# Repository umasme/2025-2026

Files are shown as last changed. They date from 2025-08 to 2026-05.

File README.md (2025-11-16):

# 🚀 NASA Lunabotics 2026 — University of Miami ASME

Robust, ROS 2–based software stack and supporting assets for our lunar excavation rover.  
This repository houses **software, hardware, simulation, datasets, and documentation** to support the NASA Lunabotics 2026 competition.  

---
## To Build
1. Download Docker
2. Open VS Code and switch to WS directory
3. Install the dev containers extension
4. Control + Shift + P to access command palette
5. Search for Dev Containers: Reopen in Container
6. Voila

## Sensors
1. D435i (TBD)
2. Oak D-lite (TBD)
3. Power sensor
4. Encoders
5. Linear encoders
6. Cameras

## Actuators
1. Four motors
2. Linear Actuators

## After Each Commit
Update DEVLOG.md with a summary of changes. Commits shall be made to the develop branch after main branch docker is working.

## 📖 Project Overview

Our rover integrates:

- **Perception** — stereo depth, object detection, terrain mapping  
- **Localization & Navigation** — SLAM, sensor fusion, path planning  
- **Autonomy** — state machines / behavior trees for excavation & hauling  
- **Control & Teleop** — motor drivers, teleop interfaces, web dashboard  
- **Simulation** — Ignition Gazebo worlds, scenarios, and URDF models  
- **Documentation** — aligned with NASA Systems Engineering (SRR, PDR, CDR, ConOps)  

---

## 📂 Repository Layout

```text
lunabotics-2025/
├─ README.md                     # Project overview (this file)
├─ LICENSE
├─ .github/workflows/            # CI/CD pipelines
├─ .devcontainer/                # VS Code Dev Containers
├─ docker/                       # Development & runtime Dockerfiles
├─ docs/                         # Documentation
│  ├─ index.md
│  ├─ ConOps/                    # SRR/PDR/CDR deliverables
│  ├─ Architectures/             # Block/state diagrams
│  ├─ MissionRules/              # Ops rules, FMEA links
│  ├─ Tutorials/                 # Step-by-step guides
│  └─ Calibration/               # Sensor/actuator calibration
├─ hardware/                     # Mechanical + electrical
│  ├─ electrical/                # Schematics, PCB, BOM
│  ├─ mechanical/                # CAD models, drawings
│  └─ configs/                   # Wiring tables, pin maps
├─ datasets/                     # Large files (via Git LFS)
│  ├─ bags/                      # ROS bag recordings
│  ├─ maps/                      # Occupancy/elevation maps
│  └─ test_scenes/               # Images, point clouds
├─ sim/                          # Simulation assets
│  ├─ worlds/                    # Ignition/Gazebo worlds
│  ├─ models/                    # URDF meshes, STL/DAE
│  └─ scenarios/                 # Scenario configs
├─ examples/                     # Cross-package & full-system demos
│  ├─ sim_demo.launch.py
│  ├─ teleop_example.md
│  └─ rviz_configs/
├─ tools/                        # Utility scripts
│  ├─ log_tools/                 # Bag→CSV, plotting
│  ├─ calibration/               # Camera/IMU calibration
│  ├─ deploy/                    # Deployment helpers
│  └─ ci/                        # CI support scripts
└─ ros2_ws/                      # ROS 2 workspace
   ├─ src/
   │  ├─ lunabotics_bringup/     # System launch & params
   │  ├─ lunabotics_description/ # URDF/Xacro and meshes
   │  ├─ lunabotics_msgs/        # Custom messages & services
   │  ├─ lunabotics_hw/          # Hardware drivers
   │  ├─ lunabotics_perception/  # Cameras, detection
   │  ├─ lunabotics_mapping/     # SLAM & maps
   │  ├─ lunabotics_localization/# State estimation
   │  ├─ lunabotics_navigation/  # Planning & control
   │  ├─ lunabotics_control/     # Low-level control loops
   │  ├─ lunabotics_mission/     # Autonomy FSM/BT
   │  ├─ lunabotics_teleop/      # Joystick / keyboard teleop
   │  ├─ lunabotics_dashboard/   # Web UI & ROS bridge
   │  └─ lunabotics_sim/         # Simulation plugins & launches
   ├─ build/                     # (ignored) colcon build output
   ├─ install/                   # (ignored) colcon install
   └─ log/                       # (ignored) colcon logs

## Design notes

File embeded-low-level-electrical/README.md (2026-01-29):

# 🚀 ASME Lunabotics 2026 University of Miami – Electrical Subsystem

Welcome to the official repository for the electrical subsystem of the University of Miami’s ASME Lunabotics team for the **2026 NASA Lunabotics Competition**.

---

This repository documents the design, implementation, and testing of the rover’s electrical system, emphasizing high reliability, efficiency, and simplicity.

# 2026 Design Goals

- Design an effective system with high reliability, minimal points of failure, and strategic redundancies while keeping it simple with minimal components and maximum efficiency.

- Focus on real-time data logging of current, voltage, power, temperature, and speed for post-analysis and future optimization.
d
- Reduce wiring complexity by using multiplexed communication protocols.

- Ensure reliable wired communication and power distribution to motors and other subsystems.
---
# 2026 Proposed Electrical Architecture

<p align="center">
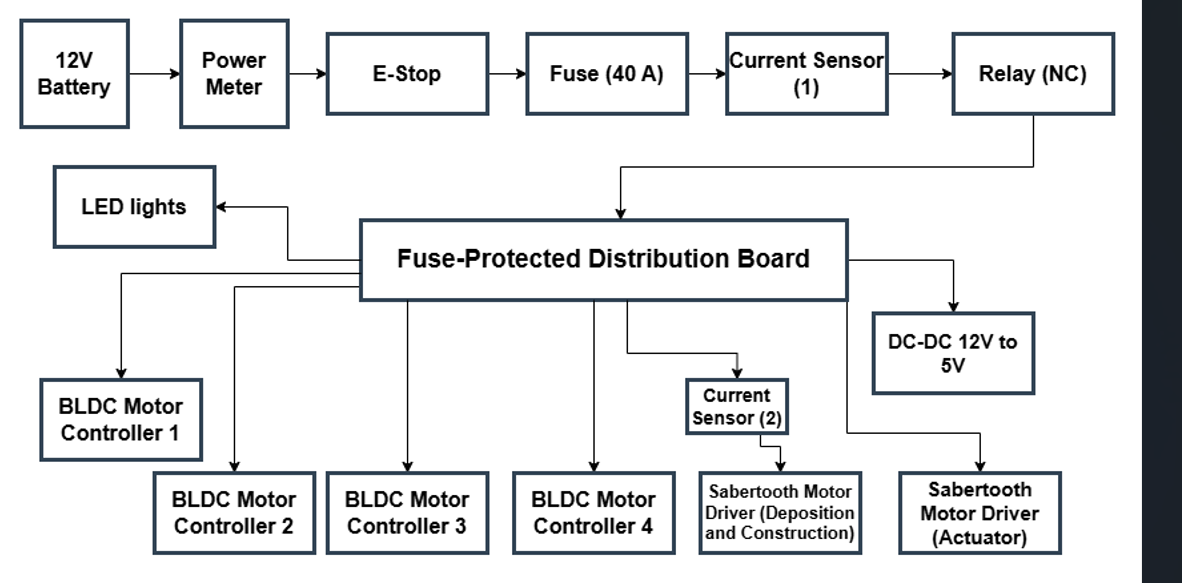
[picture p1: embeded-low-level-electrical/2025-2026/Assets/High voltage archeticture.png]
High Voltage Electrical Architecture
  
  <p align="center">
  <b> High Voltage Electrical Architecture </b>
  </p>
</p>

<p align="center">
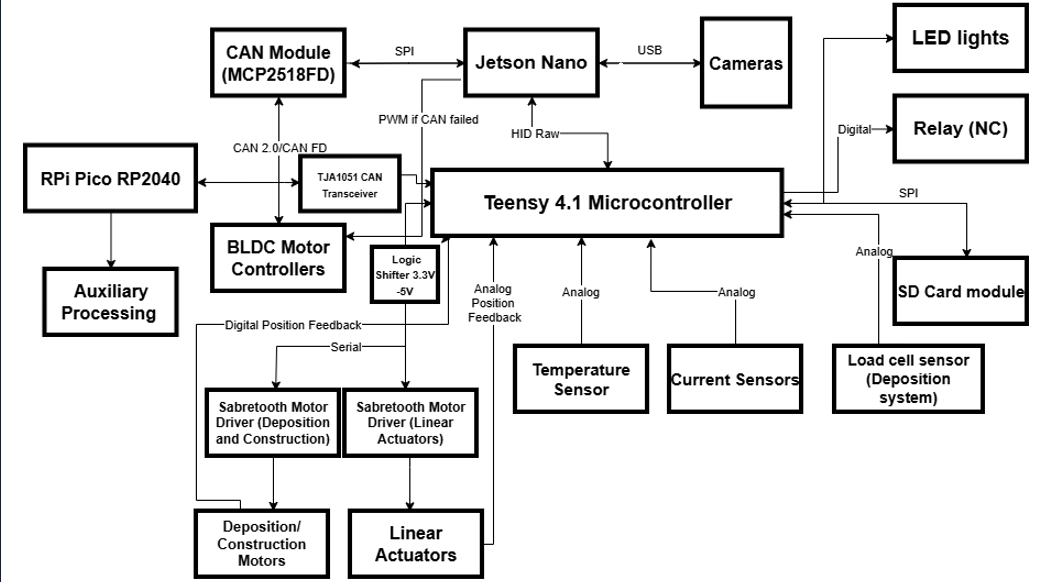
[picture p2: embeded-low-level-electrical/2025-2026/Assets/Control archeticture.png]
Control Electrical Architecture
  
</p>
  <p align="center">
  <b> Control Electrical Architecture </b>
  </p>

---
## Preliminary Design Review (PDR)

As part of the NASA Systems Engineering methodology, our team conducts a **Preliminary Design Review (PDR)** to evaluate and validate the proposed system design before detailed development.  

This review presentation includes:

1. **Responsibilities and Main Goals** – Overview of team roles and project objectives  
2. **Last Year’s System and Proposed Changes** – Comparison and improvements over the previous design  
3. **Design Overview** – High-level architecture and subsystem details  
4. **Verification Plans** – How the design will be tested and validated  
5. **Risk Matrix** – Identification and mitigation of potential risks

📄 **View the PDR presentation:**  
[Electrical PDR – ASME UM (PDF)](https://github.com/umasme/2025-2026/blob/main/embeded-low-level-electrical/2025-2026/Assets/Electrical%20PDR--%20ASME%20UM.pdf)

---
## High-Current Power Distribution Board
This high-current board distributes power to all outputs, including the four drivetrain motors, the excavation motor, the deposition motor, and two linear actuators.

<p align="center">
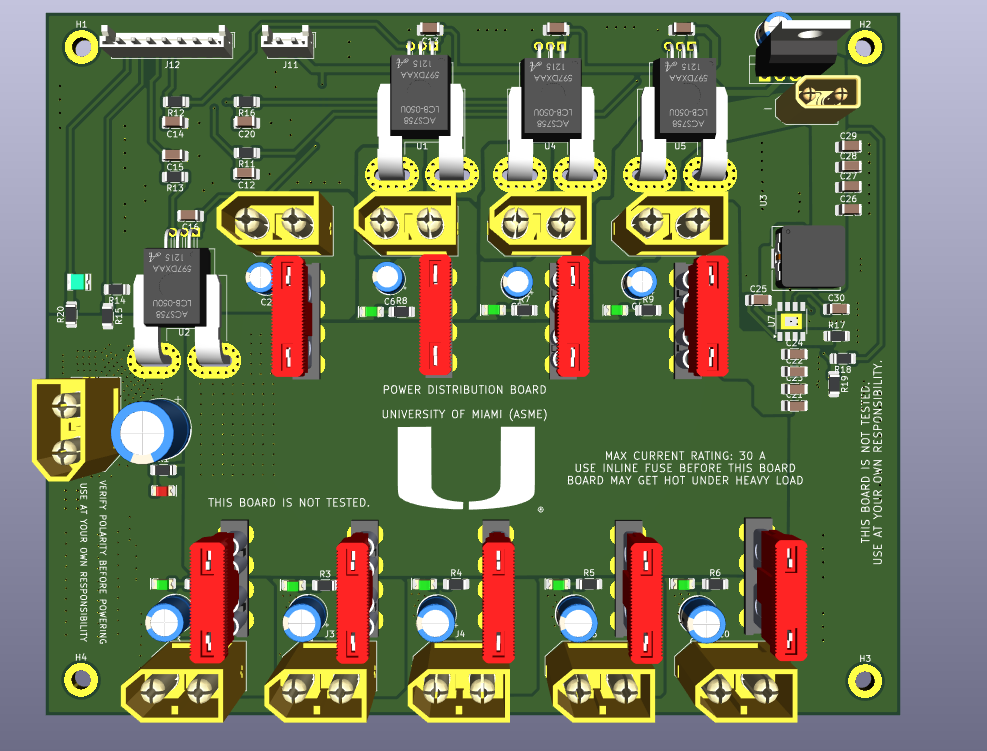
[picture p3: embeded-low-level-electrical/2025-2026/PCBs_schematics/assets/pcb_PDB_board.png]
High-Current Power Distribution Board PCB
  
</p>
<p align="center">
  <b> High-Current Power Distribution Board PCB </b>
</p>

[For more details refer to this link](https://github.com/umasme/2025-2026/tree/main/embeded-low-level-electrical/2025-2026/PCBs_schematics/ASME%20UM%20High%20current%20board%20EDIT%20HERE)

---
## Low-Level Control Board based on Teensy 4.1

<p align="center">
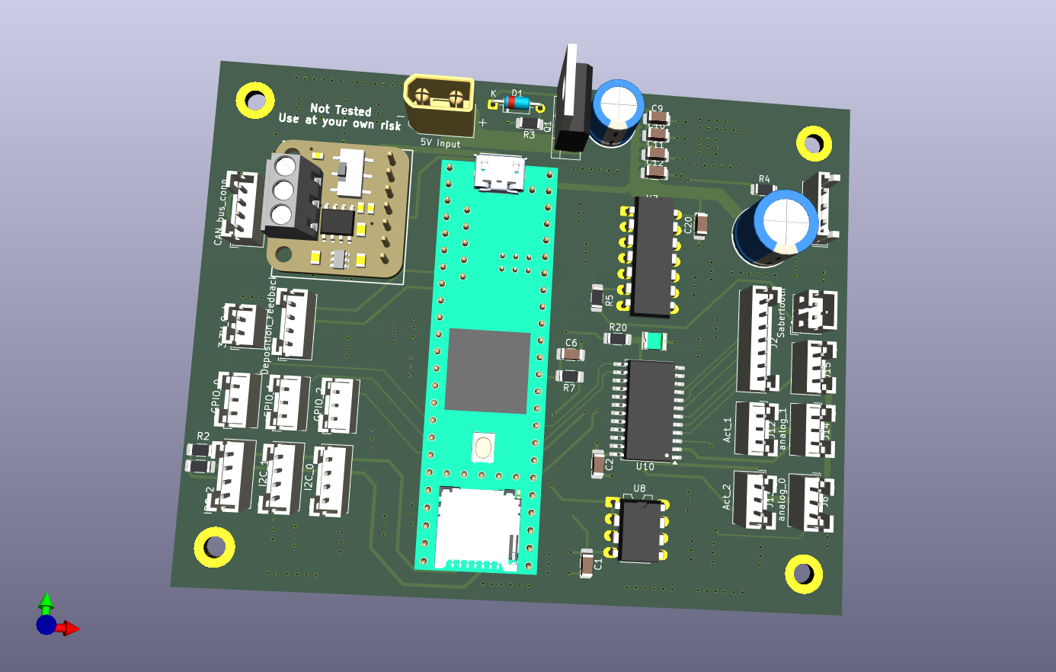
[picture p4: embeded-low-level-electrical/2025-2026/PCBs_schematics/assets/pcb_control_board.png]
Low-Level Control Board based on Teensy 4.1 PCB
  
</p>
<p align="center">
  <b> Low-Level Control Board based on Teensy 4.1 PCB </b>
</p>

[For more details refer to this link](https://github.com/umasme/2025-2026/tree/main/embeded-low-level-electrical/2025-2026/PCBs_schematics/ASME%20UM%20Control%20Board%20EDIT%20HERE)

---
##  🎯2026 Season Plan 
We finalized the season plan for 2026 for the electrical subsystem with detailed performance analysis for each part we used in the electrical system and proposed improvement.

**[Click here to access the 2025 season plan](https://www.overleaf.com/read/gmnmmjygcdmp#dd8f39)**

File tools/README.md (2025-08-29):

### Tools live here
Good tools to have: log tools, calibration, deploy, ci

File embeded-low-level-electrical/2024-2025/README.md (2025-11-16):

# 🚀 ASME Lunabotics 2025 University of Miami – Electrical Subsystem

Welcome to the official repository for the electrical subsystem of the University of Miami’s ASME Lunabotics team for the **2024 NASA Lunabotics Competition**.

---

## 📚 Table of Contents

- [Project Overview](#project-overview)  
- [Achievements](#achievements)  
- [The Rover](#the-rover)  
- [Electrical System Architecture](#electrical-system-architecture)  
- [CAN Bus System](#can-bus-system)  
- [Motor drivers (Sabertooth 2x12)](#motor-drivers-sabertooth-2x12)
- [Motor drivers (BTS7960)](#motor-drivers-bts7960)  
- [Acknowledgement](#acknowledgement)
- [2025 season plan ](#2025-season-plan)
---

## 📌Project Overview

This project highlights main work done by the electrical team of the University of Miami’s **ASME Lunabotics** for the **2024 NASA Lunabotics Competition** — a nationally recognized challenge that tasks university teams with designing and building autonomous lunar excavators capable of navigating and collecting regolith in a simulated lunar environment.

Without hesitation, the **2025 season marked a pivotal turning point** for the team. We built multiple subsystems entirely from scratch, including the complete **electrical subsystem**.
In the design process, we prioritized **simplicity and reliability**, focusing on minimizing points of failure while ensuring high performance in harsh simulated lunar conditions. 

---

## 🏆Achievements

- 🏅 **Leaps and Bounds Award** – For significant improvements in the application of systems engineering. 
- 🥉 **3rd Place in Presentation and Demonstration**  
- ⚡ **Most Energy-Efficient Team**

---

## 🤖The Rover
<p align="center">
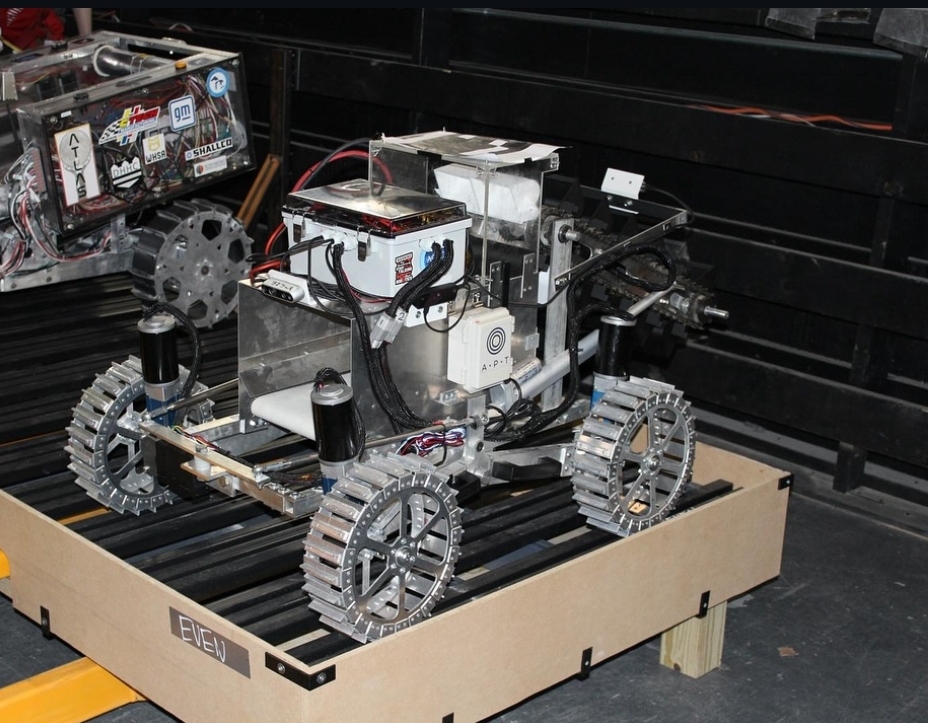
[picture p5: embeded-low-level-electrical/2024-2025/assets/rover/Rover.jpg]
Lunabotics Rover 2024
  
</p>
<p align="center">
  <b>NASA Lunabotics 2025 – Fully Assembled Rover</b><br>
  <a href="assets/">📸 See More Photos</a>
</p>

---

## ⚡Electrical System Architecture
<p align="center">
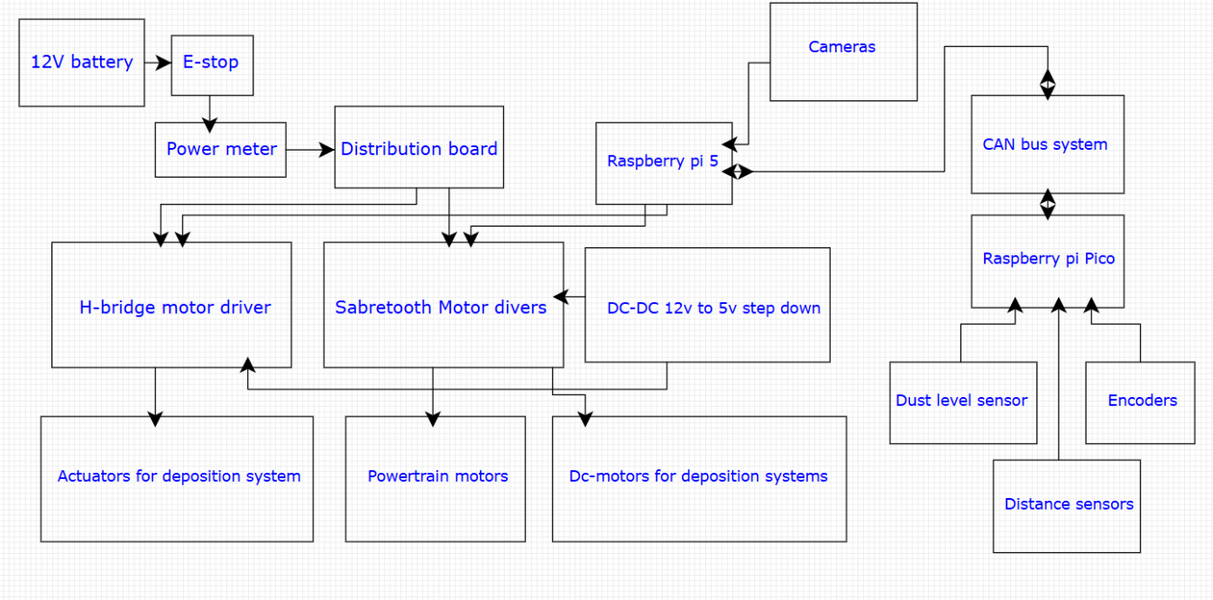
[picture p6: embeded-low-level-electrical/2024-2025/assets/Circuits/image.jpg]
  
</p>
<p align="center">
  <b> Full Simplified Circuit</b>
  </p>
  
  <p align="center">
 <br>
  <a href="assets/Circuits"> Click here to view the full detailed schematics </a>
</p>

---

## 💻 CAN Bus System

The Controller Area Network (CAN) bus is a communication protocol designed for real-time data exchange between electronic devices over a single pair of wires called CAN LOW and the other called CAN HI. Unlike traditional point-to-point serial communication, CAN uses a multi-master architecture where each node (or device) can transmit and receive messages without a central host. Messages are prioritized by IDs, enabling critical data to take precedence during high-traffic periods. CAN also includes error-checking mechanisms like CRC and automatic retransmission, ensuring communication integrity even in electrically noisy environments.  In our rover, the CAN bus linked the **Raspberry Pi** to multiple **Raspberry Pi Pico**, enabling efficient communication of data from sensors and motor encoders. We used CAN bus to reduce the computational load on the main microcontroller, allowing us to distribute this load on multiple nodes. In addition, the CAN bus allowed us to reduce the wire complexity. We used the CAN module **MCP2515** that communicates with the microcontrollers via the SPI and then sends the data through the CAN H and CAN L wires. Note: In this configration, we used the CAN classic 2.0 with data rate of 500 kbit/s.

<p align="center">
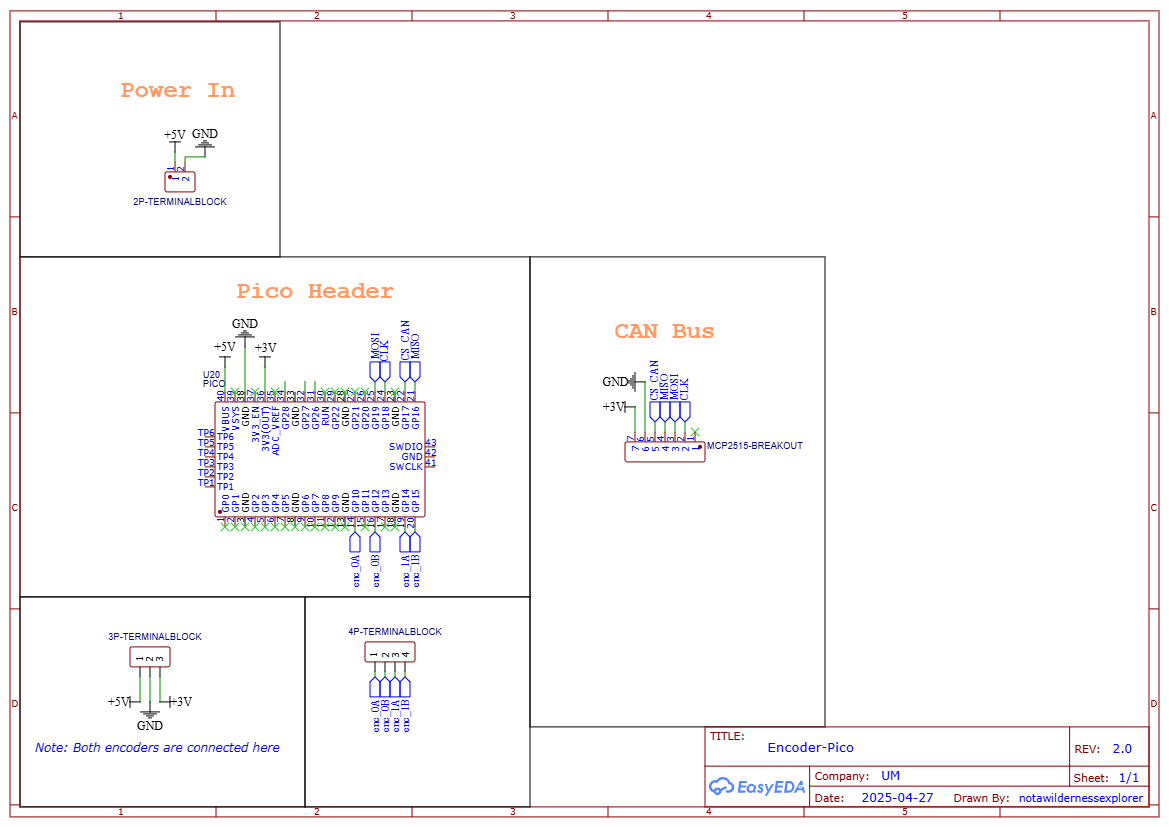
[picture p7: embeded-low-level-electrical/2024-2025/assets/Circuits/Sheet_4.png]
  
</p>
<p align="center">
  <b>CAN bus circuit</b><br>
  <a href="assets/Circuits"> See The complete CAN Circuits</a>
</p>
---
## 🧩 Hardware Setup

This section covers how to connect the MCP2515 and the encoder to the Raspberry Pi Pico.

### 🔌 Wiring

#### MCP2515 → Pico

| MCP2515 Pin | Pico Pin |
|---|---|
| MOSI | GP19 |
| SCK | GP18 |
| MISO | GP16 |
| CS | GP17 |
| VCC | 3V3 |
| GND | GND |

#### Encoder → Pico

| Encoder Pin | Pico Pin |
|---|---|
| 3V | 3.3V |
| 5V | 5V |
| Pin3 | N.C. |
| Pin4 | N.C. |
| B | GP15 |
| Pin6 | N.C. |
| A | GP14 |
| Pin8 | N.C. |
| Pin9 | N.C. |
| GND | GND |

## MCP2515 → Pi 4

| MCP2515 Pin | Raspberry Pi 4 Pin |
|---|---|
| CS | GPIO8 (CE0) |
| MOSI | GPIO10 (MOSI) |
| SCK | GPIO11 (SCLK) |
| MISO | GPIO21 (MISO) |
| INT | GPIO25 |
| VCC | 3.3V |
| GND | GND |

# 🧩 Raspberry Pi MCP2515 Setup

This guide details how to configure a Raspberry Pi to work with an MCP2515 CAN controller module by editing the system configuration file.

---

## 1. Edit the System Config File

First, open the `/boot/firmware/config.txt` file by the following command in terminal.

```bash
sudo nano /boot/firmware/config.txt
```

## 2. Add Overlay Configuration

Next, copy and paste these lines to the end of the `config.txt` file. This tells the Pi to enable the SPI interface and load the necessary driver for the MCP2515 chip.

⚠️ **Important:**

- The `oscillator` value must match the crystal on your specific MCP2515 module. Common values are `8000000` (8 MHz) and `16000000` (16 MHz). You can find this value printed on the crystal of your MCP2515 module.
- The `interrupt` value must match the GPIO pin you connected to the module's `INT` pin.

```ini
# --- MCP2515 CAN Bus Configuration ---
# 1. Enable the SPI bus
dtparam=spi=on
dtoverlay=mcp2515-can0,oscillator=8000000,interrupt=25
```

## ✅ Tips

- Use `loopback=True` first to test.
- When connecting to a real CAN bus, set `loopback=False` and `silent=False`.
- Make sure SPI pins match your Pico’s pinout.

## 📝 Full CAN bus Code with detailed instructions on how to run

👉 **[Click here](CAN%20code)**

---

# 🧩Motor drivers (Sabertooth 2x12)

The Sabertooth 2x12 is a versatile, dual-channel motor driver designed to control two DC motors with up to 12 A continuous current per channel. It supports multiple control modes, including analog, radio control (RC), and serial communication.
---
## You can not plug the Raspberry pi directly to the Sabertooth !! 

One of the challenges we faced was the voltage incompatibility between the **Raspberry Pi**, which operates at 3.3V logic, and the Sabertooth motor driver, which requires 5V logic for reliable serial communication. In the 2023 competition, the team addressed this issue by routing control signals through an **Arduino**, which acted as a 5V buffer. While this worked, it introduced unnecessary complexity and potential communication delays. To make the system simpler and reduce the points of failure, we transitioned to using compact **bi-directional logic level converters (BSS138)**, allowing us to safely and efficiently shift the 3.3V signals up to 5V. This solution maintained signal integrity and enabled direct communication between the Pi and the Sabertooth.

<p align="center">
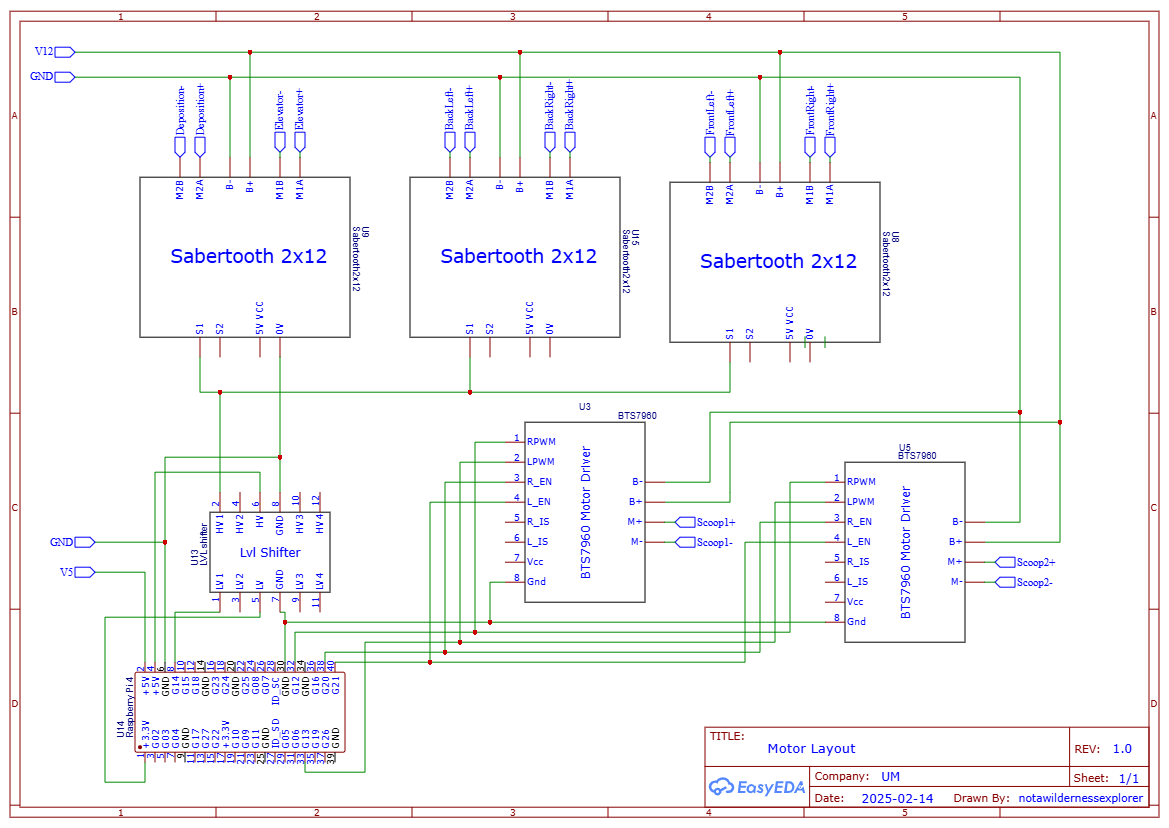
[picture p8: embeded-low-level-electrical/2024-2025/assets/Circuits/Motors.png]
  
</p>

<p align="center">
  <b>Sabertooth and H-bridge Motor Drivers Circuit Schematics </b><br>
</p>

### Sabertooth 2x12 Motor Driver Configuration

To reduce the wiring complexity, the serial mode was used. This explains how to set up the **Sabertooth 2x12** motor driver for **packetized serial mode** with default DIP switch settings and configurable address bits.

📄 [Official Sabertooth 2x12 Datasheet (PDF)](https://www.dimensionengineering.com/datasheets/Sabertooth2x12.pdf)

### ✅ Fixed DIP Switch Settings (#1–#3)

Always make sure the first three DIP switches are set as follows:

| Switch | Position | Purpose |
|:---:|:---:|---|
| 1 | DOWN | Serial mode enabled |
| 2 | DOWN | Baud rate set to 9600 bps |
| 3 | UP | Address bit (fixed) |

### 🔄 Configurable DIP Switches (#4–#6)

Use switches **#4–#6** to set the **serial address**.  
These switches work together with Switch #3 (which is always UP) to define the final address. The documentation above has detailed configration for these switches.

### 🔧 Sample code for testing

To test the motors, we wrote a script using the `pysabertooth` library. Each Sabertooth was initialized with a unique address. This script demonstrates safe testing under current limitations and includes logic for bidirectional control.

```python
from pysabertooth import Sabertooth

# Initialize Sabertooth motor driver on address 128
motor1 = Sabertooth("/dev/serial0", baudrate=9600, address=128)
motor1.open()
motor1.drive(1, 60)  # Drive motor 1 at 60% power
motor1.drive(2, 60)  # Drive motor 2 at 60% power
```

👉 View the full motor test script [here](Main%20codes/motor_testing.py)

---

## 🧩Motor drivers (BTS7960)

---
The BTS7960 is a high-power H-bridge motor driver module capable of driving DC motors with currents up to 43A. This motor driver support speed and direction control via PWM signals. These drivers had beem used to control the linear actuators. 
<p align="center">
  Lunabotics Rover 2024
</p>

<p align="center">
  <b> Sabertooth and H-bridge Motor Drivers Circuit Schematics </b><br>
</p>

| **Pin Name** | **Description** |
| --- | --- |
| **L\_EN** | Left side enable pin (enable left half-bridge) |
| **R\_EN** | Right side enable pin (enable right half-bridge)  |
| **L\_PWM** | Left side PWM input (controls direction/speed) |
| **R\_PWM** | Right side PWM input (controls direction/speed) |
| **RPWM / LPWM** | Alternative labeling for direction control inputs |
| **VCC** | 5V logic power input |
| **GND** | Ground |
| **Motor+** | Motor positive terminal |
| **Motor-** | Motor negative terminal |
| **B+** | Battery positive (motor power input) |
| **B-** | Battery negative (ground) |

If you want to reduce the wiring complexity, you can just PULL L_EN, R_EN, and VCC to be high, and then you can easily control the speed of the actuator by the PWM from only two pins from the PI.

**[Click here to access the test script to run the actuators using H-bridge motor driver](Main%20codes/Actuator.py)**

## 🙏Acknowledgement 

This project was completed under the direct supervision, direct contribution, and mentoring of Russel Roberts, a third-year PhD student studying Physics at the University of Miami. Special thanks for the guidance, expertise, and support provided throughout the development and testing process of this project.

##  🎯2026 Season Plan 
We finalized the season plan for 2026 for the electrical subsystem with detailed performance analysis for each part we used in the electrical system and proposed improvement.

**[Click here to access the 2025 season plan](https://www.overleaf.com/read/gmnmmjygcdmp#dd8f39)**

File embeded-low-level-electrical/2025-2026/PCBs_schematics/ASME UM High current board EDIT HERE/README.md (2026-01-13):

# High-Current Power Distribution Board (PDB)

## Overview
The High-Current Power Distribution Board (PDB) is designed to safely and efficiently distribute electrical power to all high-power subsystems of the rover. It serves as the central power hub, handling high transient currents while providing protection, diagnostics, and future expandability.

## Final Board Design
 Hey!

## Supported Loads
This board distributes power to the following subsystems:

* **4×** Drivetrain motors (BLDC)
* **1×** Excavation motor (BLDC)
* **1×** Deposition motor (DC)
* **2×** Linear actuators 

> **Note:** The Jetson Nano is powered through an external power supply with a dedicated DC-DC converter and is **not** powered directly from this board.

## Electrical Capabilities
* **Peak Current:** Supports up to **40 A** peak current during startup and transient conditions.
* **Output Configuration:**
  * Minimum of **7** high-current outputs.
  * **1** dedicated output for a DC-DC converter.

## Board Features
* **Protection:** Reverse-polarity protection on the main power input and individual fuses for each output bus. (To be added)
* **Diagnostics:**
  * Power indication LED for board power status.
  * Individual LED indicators for each output to identify blown or faulted fuses.
* **Stability:** Decoupling capacitors for voltage stability and noise reduction.
* **Mechanical:** Defined mounting holes for secure mechanical integration.
* **Current Sensing:**
  * Initial revision includes main bus current sensor (or limited sensors).
  * PCB design preserves expandability for future per-output current sensing.
* ** Add-ons:**
  * Onboard DC-DC buck converter based on AP64502Q synchronous DC-DC buck converter (5V/5A). 
  * Linear 3.3 V regulator (not required for current system architecture).

## PCB Design Considerations
* **High-Current Optimization:** Adhered to IPC-2221 standards for power plane optimization to handle high-current loads and manage thermal dissipation.
* **Component Layout:** Strictly followed the recommended layout guidelines specified in the [AP64502Q DC-DC Converter Datasheet](https://www.diodes.com/datasheet/download/AP64502Q.pdf) to minimize noise and ensure stability.
* **Power Integrity Analysis:** Utilized Altium's Power Analyzer tool to simulate current density and eliminate bottlenecks.
<h3>Power Analyzer Results</h3>
<table width="100%">
  <tr>
    <th width="50%">Before Optimization</th>
    <th width="50%">After Optimization</th>
  </tr>
  <tr>
    <td align="center">
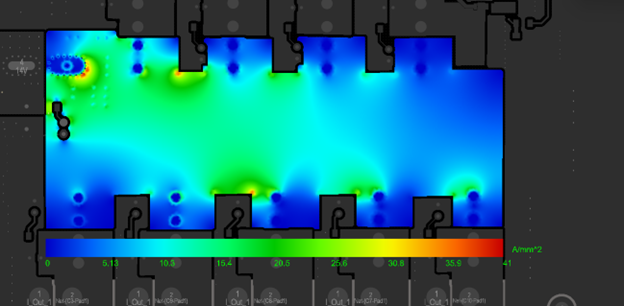
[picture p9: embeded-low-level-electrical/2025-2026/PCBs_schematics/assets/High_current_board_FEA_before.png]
Before
      
    </td>
    <td align="center">
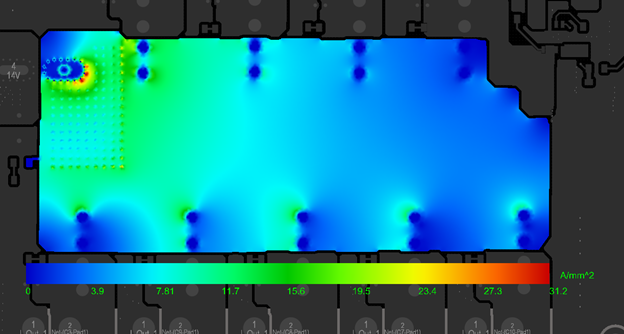
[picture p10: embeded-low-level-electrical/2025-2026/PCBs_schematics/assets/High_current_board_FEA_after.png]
After
      
    </td>
  </tr>
</table>

## Design Objectives
* **Reliability:** Consistent operation under high-current and transient conditions.
* **Efficiency:** Low-resistance power paths to minimize voltage drop.
* **Usability:** Clear visual diagnostics for fast fault identification.

## Safety and Protection
* **Input:** Reverse-polarity protection.
* **Output:** Fuse protection per channel.
* **Visuals:** Fault detection via LED indicators.
* **Noise:** Electrical noise suppression using decoupling capacitors.

## Please Stay Tuned for the fabrication and prototyping

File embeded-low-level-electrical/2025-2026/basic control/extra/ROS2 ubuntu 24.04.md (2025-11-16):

✅ **Here is the installation procedure for ROS 2 Jazzy on a Raspberry Pi 5:**

1. Burn **Ubuntu 24.04 LTS** onto the Raspberry Pi 5 using the **Raspberry Pi Imager**.
2. Follow the installation procedure here: [ROS 2 Jazzy Installation Guide](https://docs.ros.org/en/jazzy/Installation/Ubuntu-Install-Debs.html).
3. When you finish the installation, type `ros2` in the terminal. If it doesn’t work, it’s probably because you still need to source your workspace.
4. Install **gedit** using this command:

   ```bash
   sudo apt update
   sudo apt install gedit -y
   ```
5. Then open `.bashrc` with:

   ```bash
   gedit ~/.bashrc
   ```

   At the end of the file, add:

   ```bash
   source /opt/ros/jazzy/setup.bash
   source ~/ros2_ws/install/setup.bash
   ```

   *(Add the `~/ros2_ws` line only if you have already created and built a workspace.)*
6. Save the file, then type `source ~/.bashrc` to reload it. Now, typing `ros2` in the terminal should work.

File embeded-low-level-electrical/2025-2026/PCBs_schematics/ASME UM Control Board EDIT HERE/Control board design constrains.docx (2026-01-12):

Hi,

In our design we need another low-level control board, which is supposed to have mainly Teensy 4.1 and motor drivers’ controls.

### 1. Core Architecture & Power

- Microcontroller: The board shall utilize a Teensy 4.1 as the primary controller.
- Power Input: The system shall be powered by a 5V DC input from an external Power Distribution Board (PDB).
- Voltage Regulation: The board shall provide a stable 3.3V output rail for external sensors and peripherals.
- Power Integrity: Decoupling capacitors shall be placed at all IC power pins and across power rails to ensure signal stability and suppress high-frequency noise.

### 2. Communication & Motor Control

- I2C Bus:
  - Provide headers for up to three (3) I2C interfaces.
  - Each shall include integrated pull-up resistors sized for the target bus speed.
- SPI Bus:
  - Include a dedicated SPI interface with PCB layout considerations for impedance control and trace length matching.
- CAN Bus:
  - Include a CAN interface utilizing the Teensy 4.1 FlexCAN controller (requires an external transceiver).
- Sabertooth Interface:
  - Provide a dedicated Serial communication interface for Sabertooth motor drivers.
- Logic Level Shifting:
  - Please follow the recommended layout from the TI.
  - Implement unidirectional logic level shifter (SN74AHCT125N) to convert 3.3V Teensy logic to 5V for:
    - Digital LED control signals.
    - Sabertooth motor driver logic (where required).

### 3. Specialized Actuator & Sensor I/O

- Deposition Motor Encoders:
  - Provide a 6-pin interface for motor encoders. This interface shall operate on 3.3V logic as per validated testing.
- Linear Actuators: Support two (2) linear actuators via two 3-pin interfaces.
  - Feedback: The system shall utilize analog input for position feedback from the actuators.
- Analog Inputs: Provide at least five (5) analog input pins (including actuator feedback).
- Signal Conditioning: Implement Op-Amp voltage buffers for high-impedance inputs (e.g., voltage dividers).
  - Note: Active RC filtering is excluded; local decoupling for the Op-Amp IC is mandatory.
- PWM & Interrupt: Include at least one (1) dedicated PWM interface.
  - Reserve a minimum of two (2) interrupt-capable digital pins for E-Stop relay control or limit switches.
- LED lights: Add a capacitor and a resistor to prevent signal reflection on the data signal pin.

### 4. Physical & PCB Design Requirements

- Connectors: All off-board connections shall utilize JST 2.54mm (0.1") connectors for secure, standardized interlocking.
- PCB Stackup: Top Layer: Primary signal routing and component placement.
  - Bottom Layer: Dedicated Ground Plane to minimize EMI and provide a low-impedance return path.
- Trace Geometry: Trace widths shall be calculated using the IPC-2221 standard to ensure manufacturing reliability and mechanical durability, regardless of current load.

Do we need Op amp before the ADC?

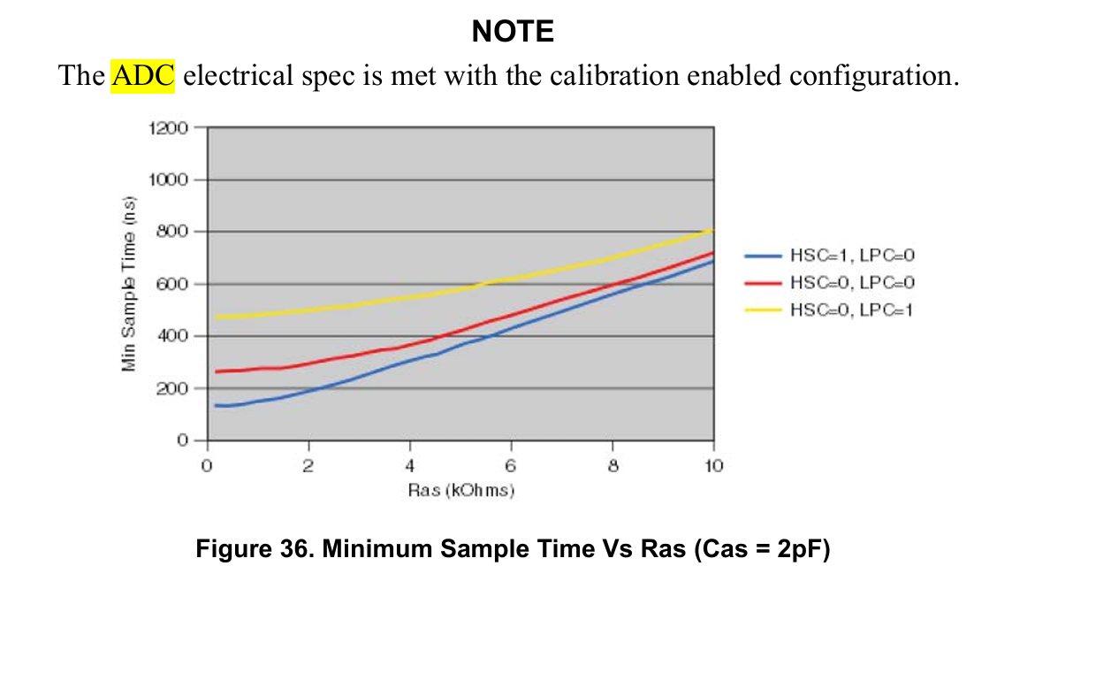
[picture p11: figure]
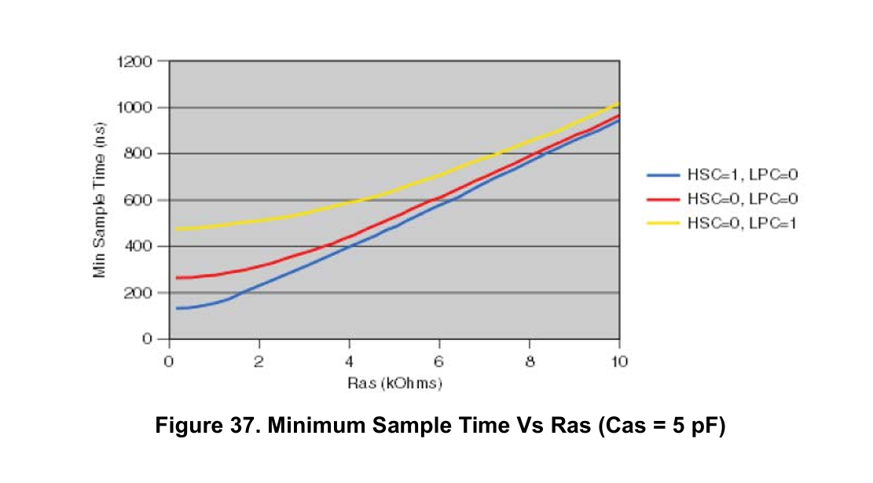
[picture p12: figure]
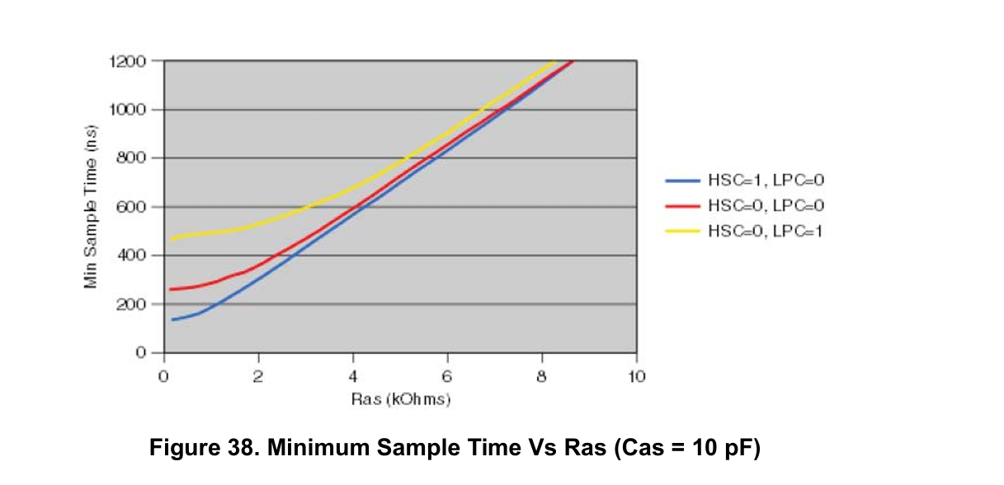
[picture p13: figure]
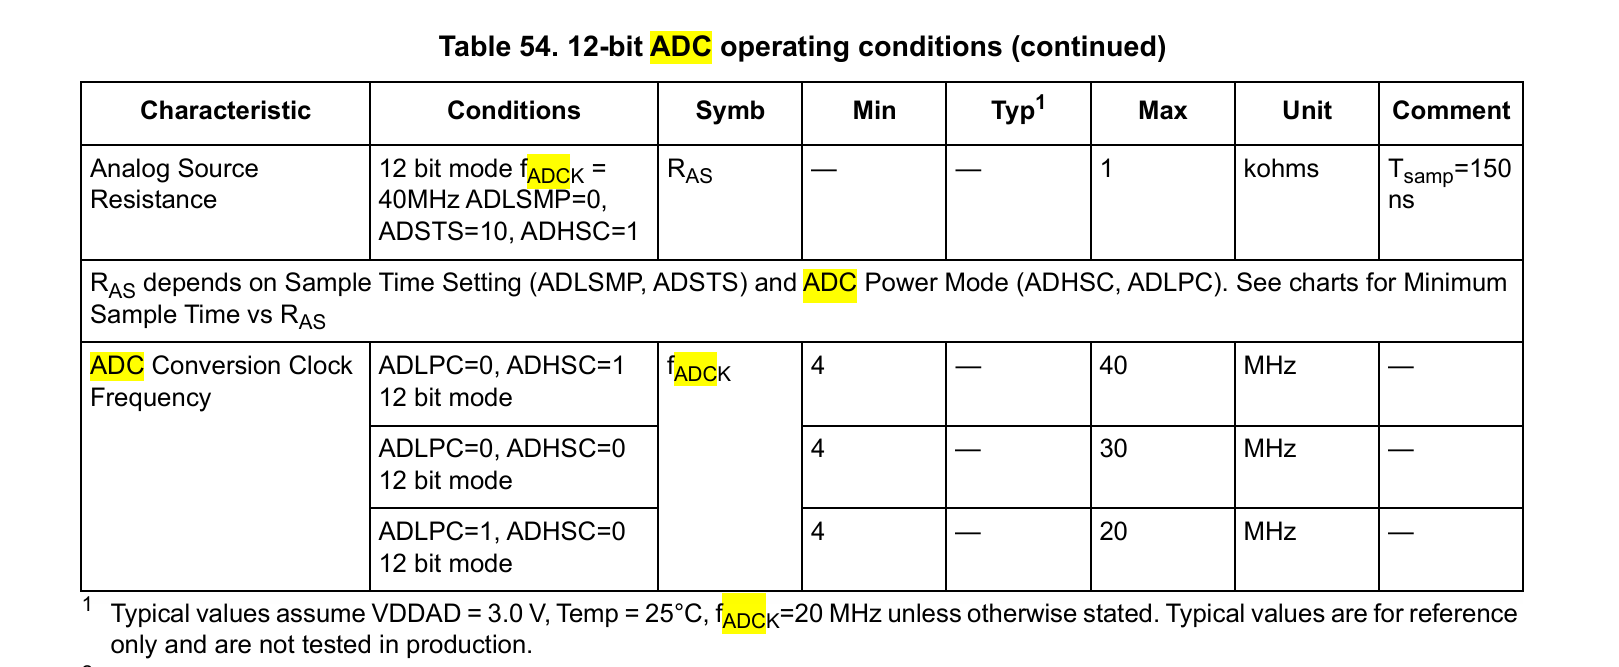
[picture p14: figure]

First of all, there are no pull up resistors on the evaluation board. What about the internal pull up resistors?

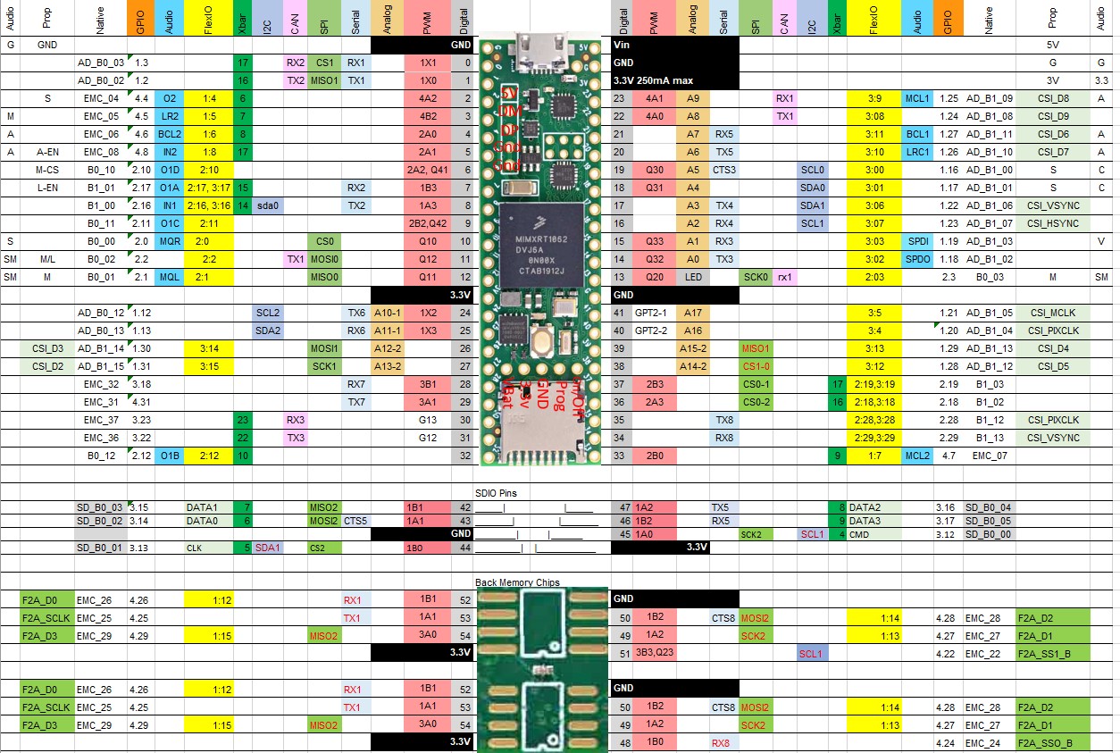
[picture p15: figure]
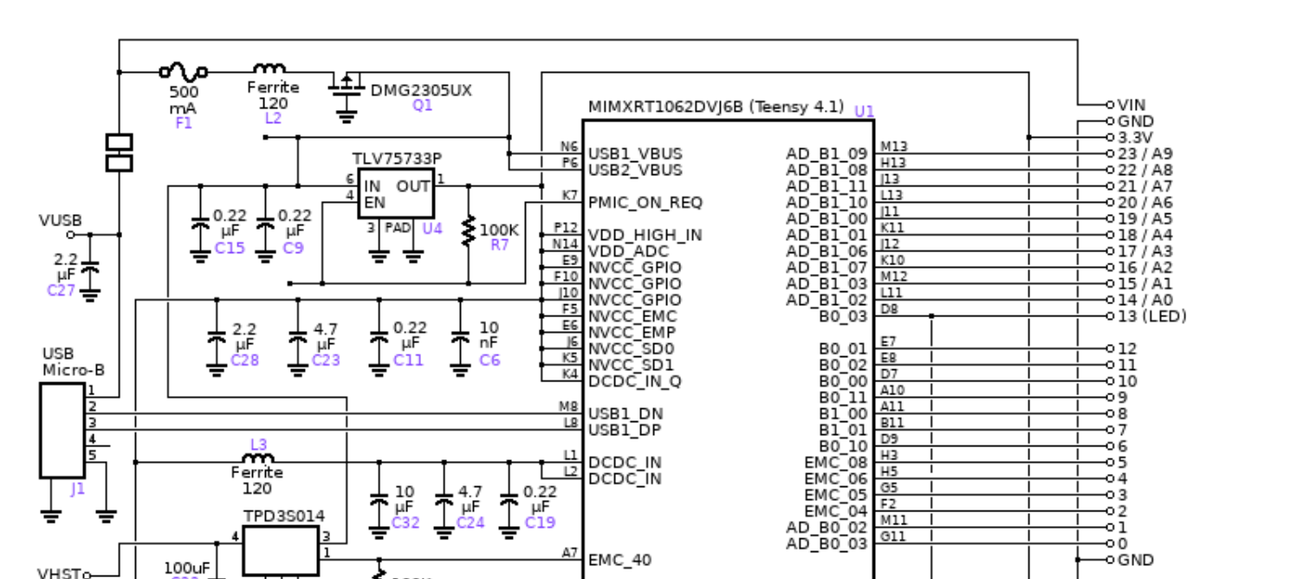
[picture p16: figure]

Teensy and Teensy++ Schematic Diagrams (https://www.pjrc.com/teensy/schematic.html)

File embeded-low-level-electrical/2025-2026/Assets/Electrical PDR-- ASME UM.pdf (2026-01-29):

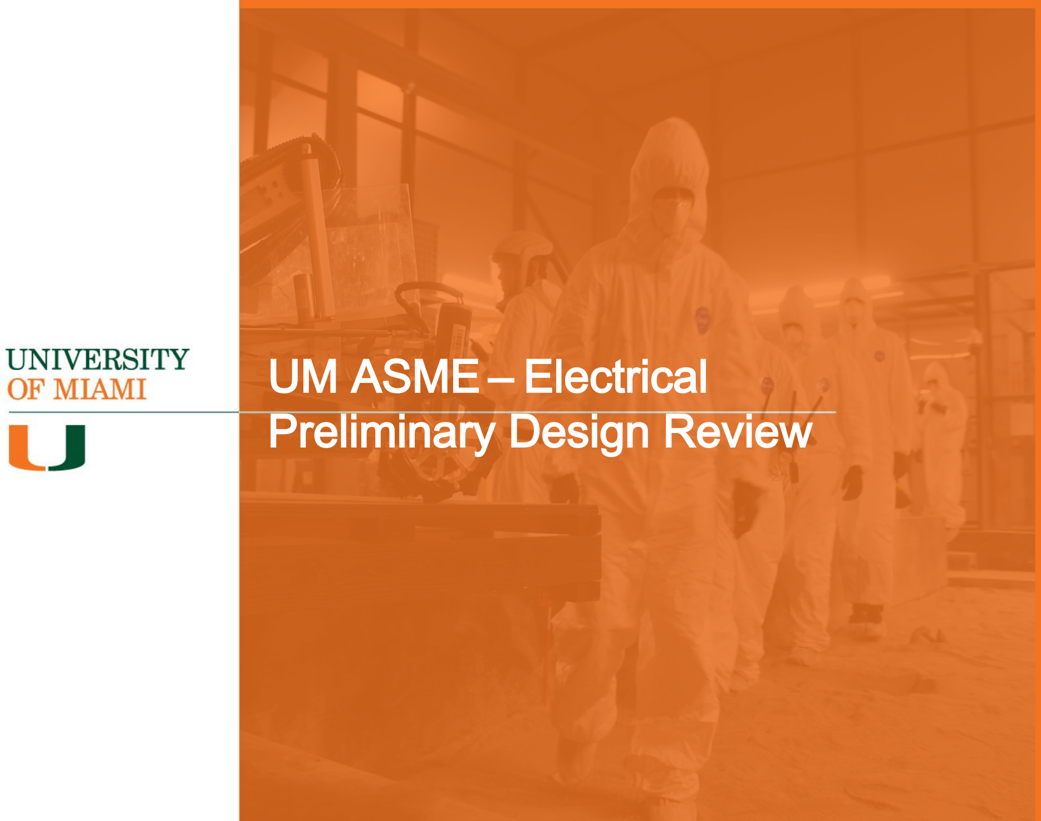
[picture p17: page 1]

# UM ASME – Electrical Preliminary Design Review

# Agenda

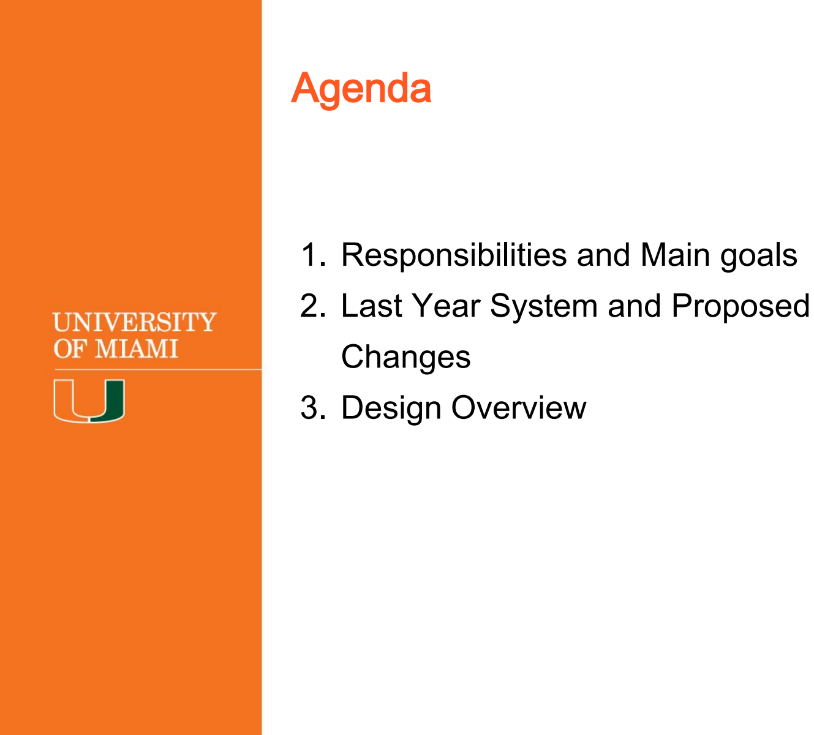
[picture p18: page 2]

# 1. Responsibilities and Main goals 2. Last Year System and Proposed Changes 3. Design Overview

# Electrical Objectives

Our main Objectives are:
1. Design an effective electrical system with high reliability, minimal points of failure, and redundancies while keeping it simple with minimal components and maximum efficiency.
2. Work closely with software and mechanical sub teams to achieve project goals.
3. Focus on real-time data logging of current, voltage, power, temperature, and speed for post-analysis and future optimization.
4. Reduce wiring complexity by using multiplexed communication protocols.
5. Ensure reliable wired communication and power distribution to motors and other subsystems.

# Last Year’s system

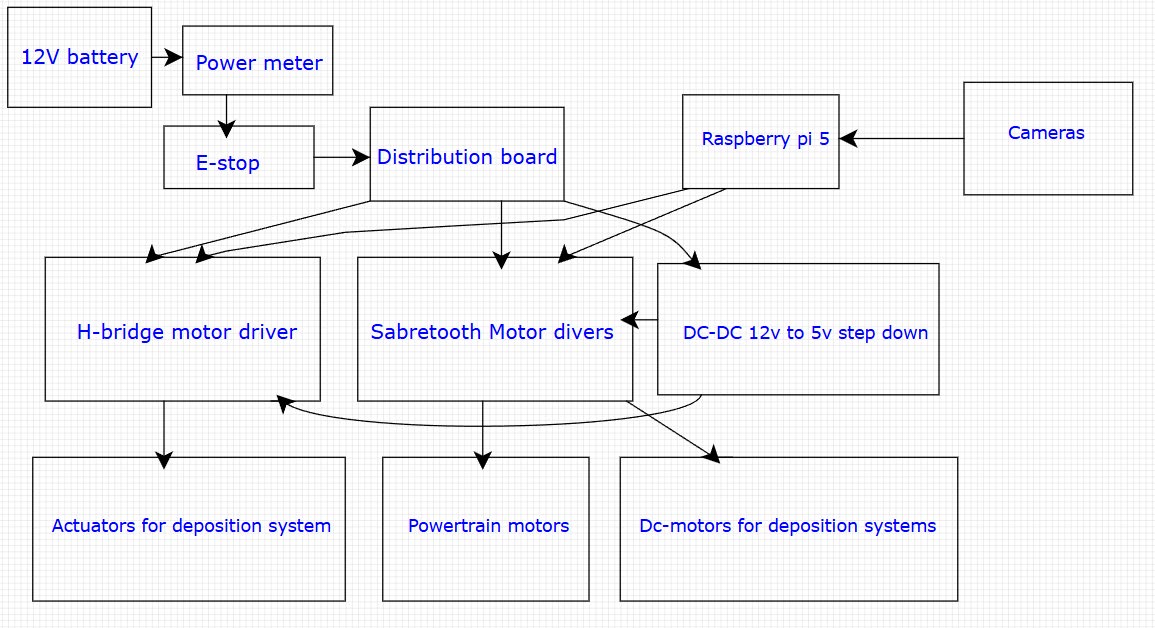
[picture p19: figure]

# Last Year’s system: Challenges and Proposed Changes

CAN Bus Interface:
Challenge
- Logic-level voltage incompatibility between the MCP2515 CAN module and the microcontroller
Solution
- Replaced MCP2515 with MCP2518FD
- Utilized the built-in CAN controller of the Teensy
- Used CAN-to-USB for communication with the main computer (Jetson Nano) via SocketCAN
- Integrated TJA1051T/3 (Adafruit) CAN transceiver
- Includes a built-in logic level shifter
- Ensures reliable voltage compatibility with the CAN

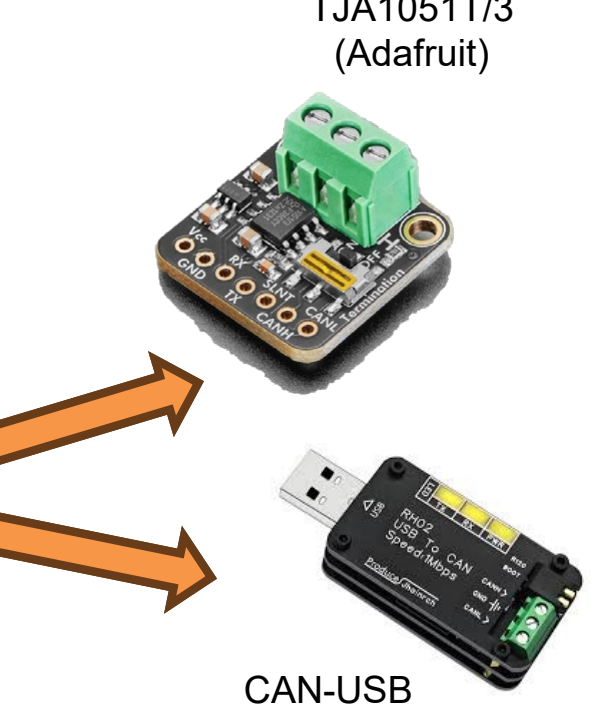
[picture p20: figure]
CAN-USB; (Adafruit)

bus | The Same VCC

MCP2515

TJA1051T/3

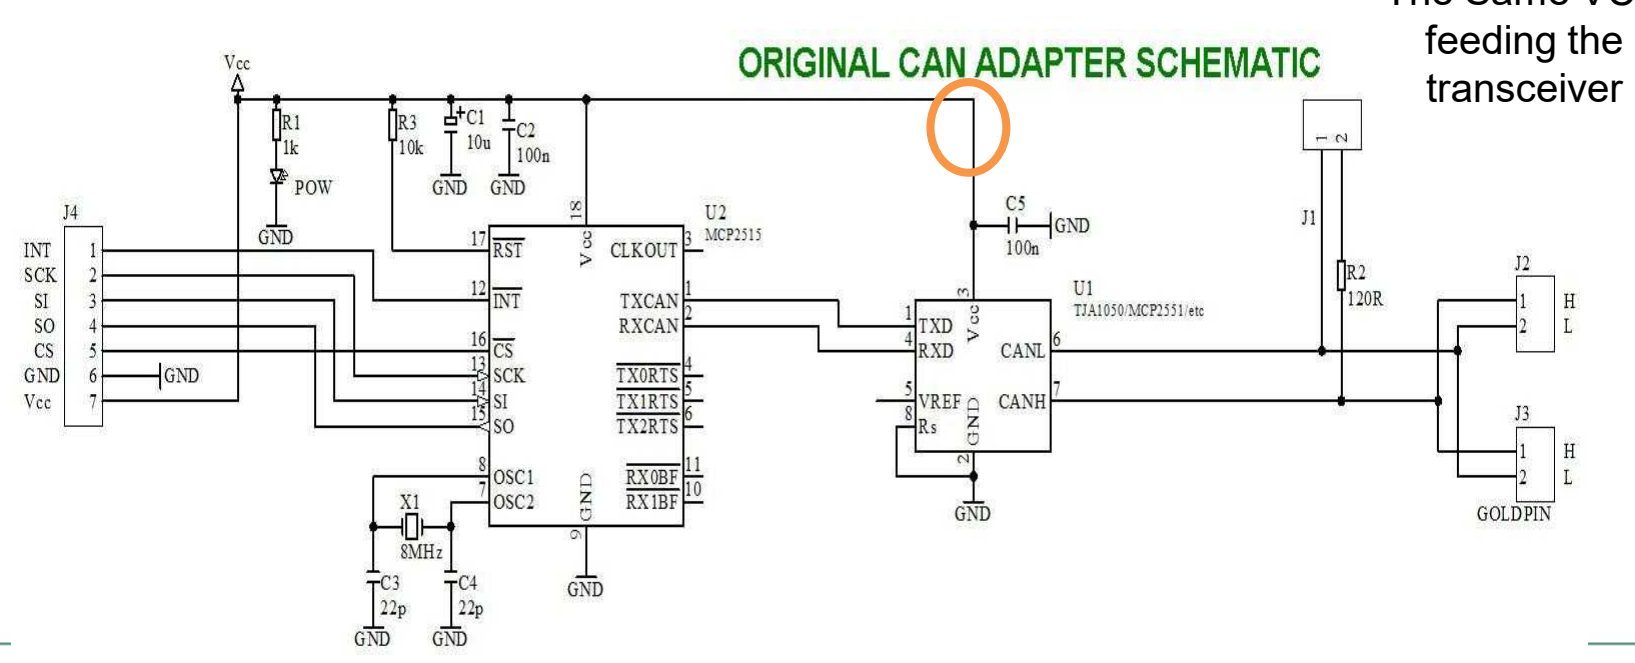
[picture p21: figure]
feeding the transceiver

# Last Year’s system: Challenges and Proposed Changes

Drivetrain motors:
Challenge
- Previous DC motors were heavy, inefficient, and lacked encoders for motion feedback
Solution
- Replaced CIM DC motors with REV Robotics BLDC 1.1V. Key Advantages
- ~60% weight reduction
- ~10% higher efficiency
- Built-in encoder for precise speed and position feedback
- CAN bus communication
- Integrated PID control within the motor controller
- Smaller physical footprint

BLDC Rev
robotics NEO
1.1V

CIM DC motor

# Last Year’s system: Challenges and Proposed Changes BLDC motors

The main issue we are facing is controlling the BLDC motors with CAN bus system. This includes reverse engineering the CAN addresses control and heartbeat signals. We could find the documentation which outlines the addresses for each functionality inside this motor controller as you see below
The team could successfully control the motors

# Last Year’s system: Challenges and Proposed Changes: BLDC motor

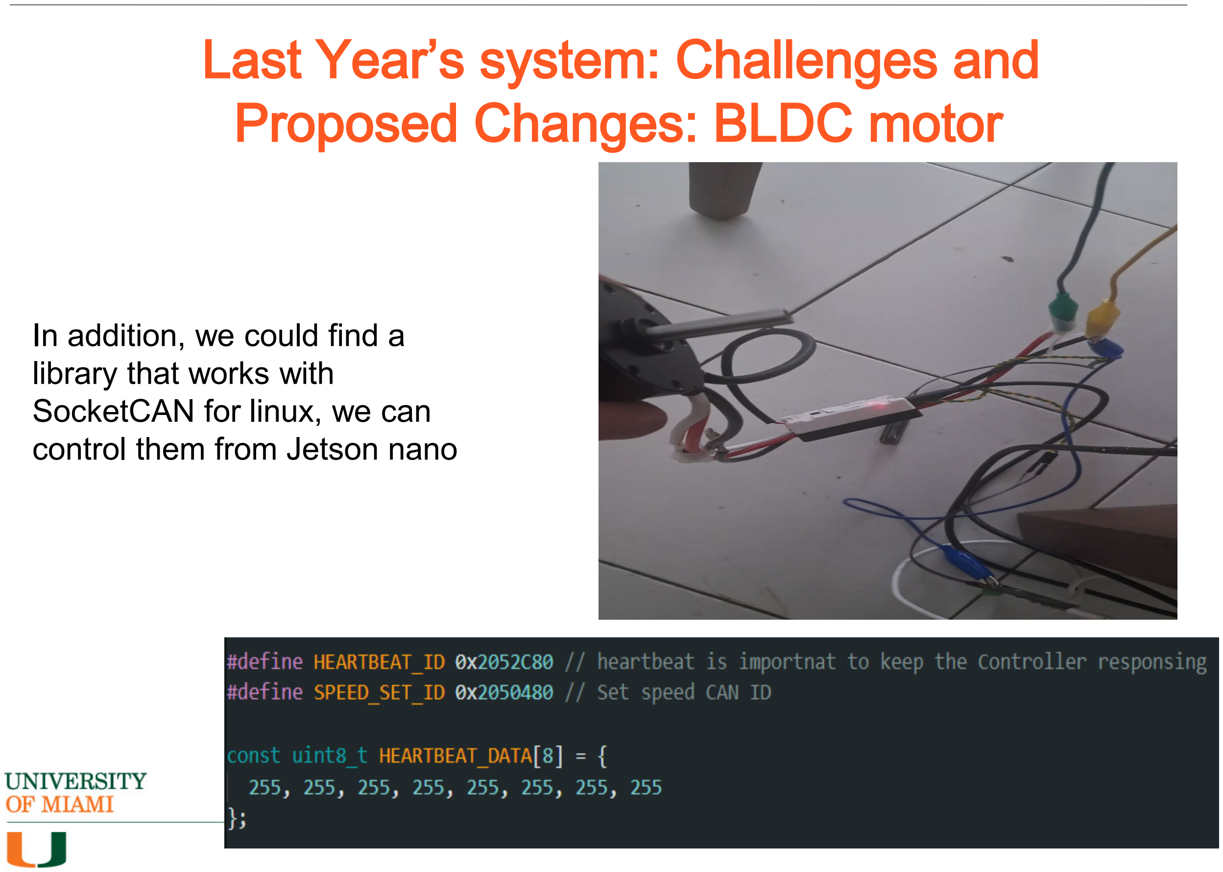
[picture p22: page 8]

### In addition, we could find a library that works with SocketCAN for linux, we can control them from Jetson nano

# Last Year’s system: Challenges and Proposed Changes

Deposition Motor:
Challenge
- Previous DC motor lacked encoders for motion feedback Solution
- Replaced with the same motor with Encoders.

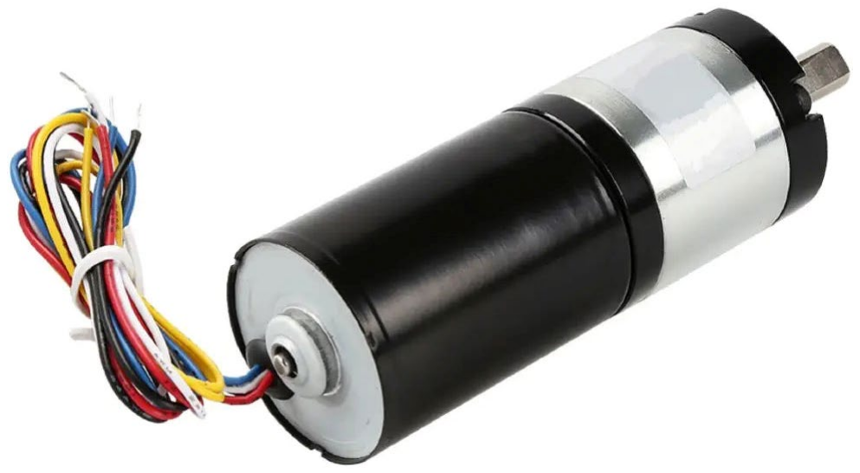
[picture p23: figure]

# Last Year’s system: Challenges and

Batteries : | Proposed Changes

Challenge

Previous LiFePO₄ batteries suffered from:

•Low energy density
•Limited discharge current, restricting motor performance
Solution

Replaced LiFePO₄ batteries with LiPo (Lithium-Polymer) drone batteries

Key Advantages
- 50%–80% higher energy density
- ~50% faster charging time
- Extremely high discharge rate (high C-rating)
→ Supports high motor current demand and rapid acceleration

BLDC Rev
robotics NEO
1.1V

Li-Ion battery

# Electrical Architecture

### 1. High-Current Power Subsystem

Handles power generation and distribution for high-load components. It includes:
- Battery
- Power Distribution Board (PDB)
- Fuses and protection circuitry
- DC-DC converters.

### 2. Low-Voltage Control Subsystem

Responsible for system intelligence, control, and communication. It includes:
- Microcontroller
- Control board
- All control logic and internal communication within the system

### 3. Electrical Interconnects & Enclosure Subsystem

Provides mechanical protection and reliable electrical connectivity. It includes:
- Electrical harnesses
- Electrical connectors
- Electrical enclosure (electrical box)

# Electrical Architecture: High-Current Power Subsystem

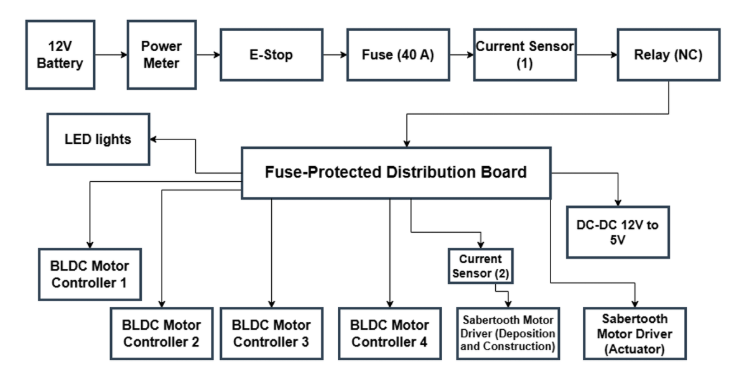
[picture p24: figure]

# Electrical Architecture: High-Current Power Subsystem: PDB


Power Distribution Board (PDB) — Main Functionalities

- Handles up to 40 A peak current during startup and transient conditions
- Provides 7 high-current outputs + 1 dedicated DC-DC converter output
- Fuse protection on each power bus
- Main bus current sensing
- integrated DC-DC buck converter 5V/5A
- Strictly follow the guidelines for the current IPC-2221/IPC-2152 for trace width and copper pour.
- Used the Power analysis tool in Altium to define the areas of high current densities

# PDB: Schematics


# PDB: Schematics: Continued


# PDB: PCB Continued


# PDB: PCB Continued


# PDB: PCB Continued


# PDB: PCB Continued

Before Optimization
- Several high-current hotspots (red/yellow regions) observed
- Current crowding at trace bottlenecks and sharp corners
- Uneven current distribution → potential localized heating and voltage drops.

After Optimization
- High-current hotspots eliminated
- Current evenly distributed across the plane
- Lower current density in critical areas → improved thermal safety
Achieved by:
- Widening traces in high-current regions
- Adding copper pours/planes for better distribution
- Smoothing corners and removing bottlenecks
- Re-routing connections for more uniform flow


# Electrical Architecture: Low Voltage/logic

# Electrical Architecture: Low Voltage/logic


Main Functionalities of the control board are:

- Teensy 4.1 microcontroller with 5V input, regulated 3.3V output, and decoupling for stable operation.
- Supports I2C, SPI, CAN, and serial interfaces for sensors and Sabertooth motor drivers, with logic level shifting for 3.3V 5V signals.
- Interfaces for motor encoders, linear actuators, analog sensors, PWM outputs, interrupt pins, and LED.
- Standard JST connectors, four-layer PCB with two ground plane for low-EMI operation.
- Followed the IPC-2221/IPC-2152 for trade width.

# Control Board: Schematics


# Control Board: Schematics


# Control Board: Schematics


# Control Board: PCB


# Control Board: PCB


# Electrical harnesses and connectors


# Electrical harnesses and connectors


# Electrical Enclosure


# Thank You!

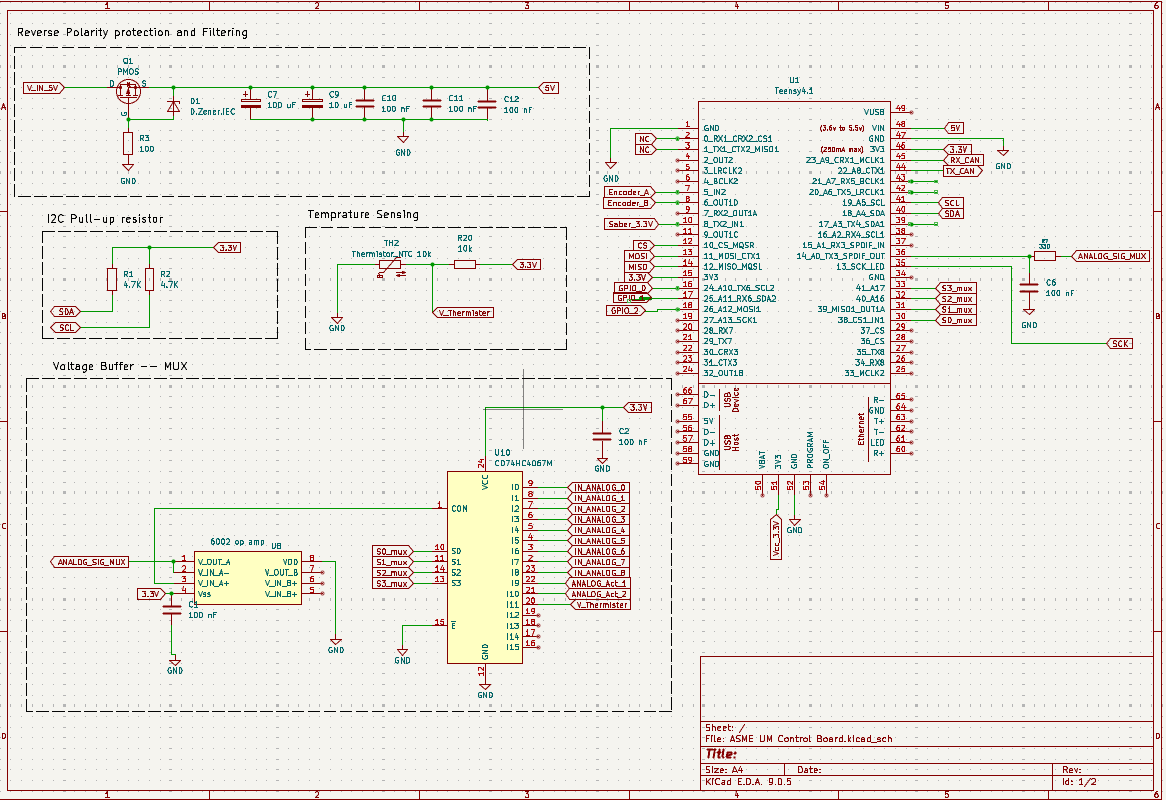
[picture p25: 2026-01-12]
embeded-low-level-electrical/2025-2026/PCBs_schematics/assets/Control_board_schematics.png

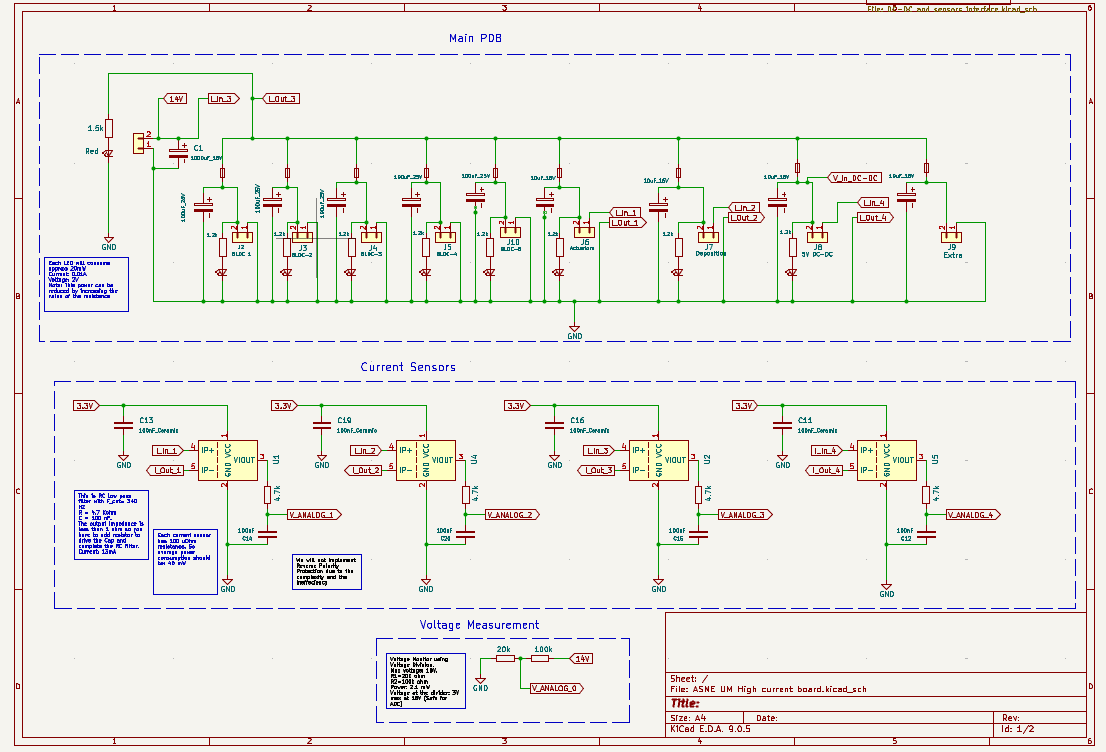
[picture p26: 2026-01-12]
embeded-low-level-electrical/2025-2026/PCBs_schematics/assets/PDB_board_schematics.png

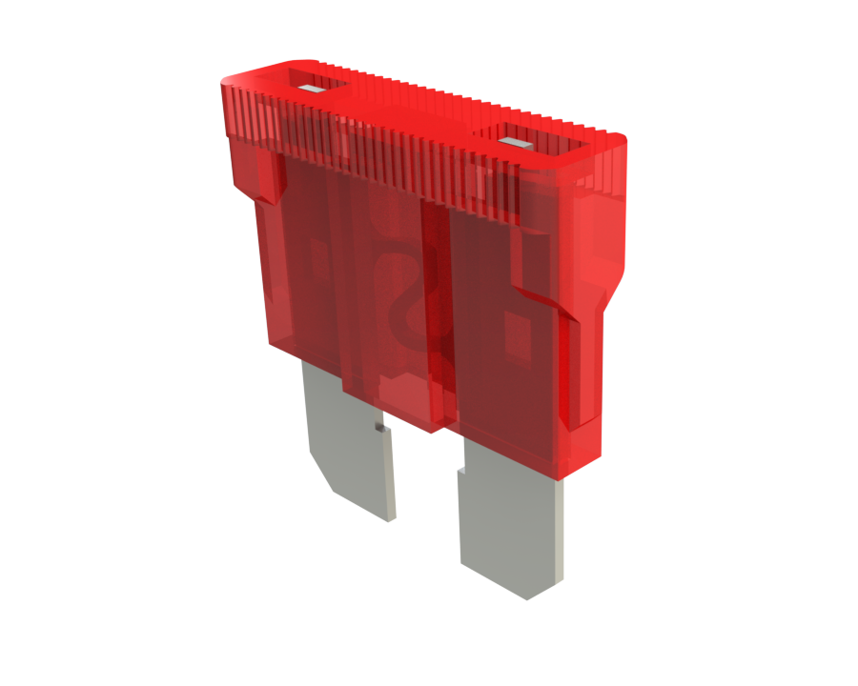
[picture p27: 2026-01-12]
embeded-low-level-electrical/2025-2026/PCBs_schematics/ASME UM High current board EDIT HERE/Footprints/fuse-automotive-10a.png

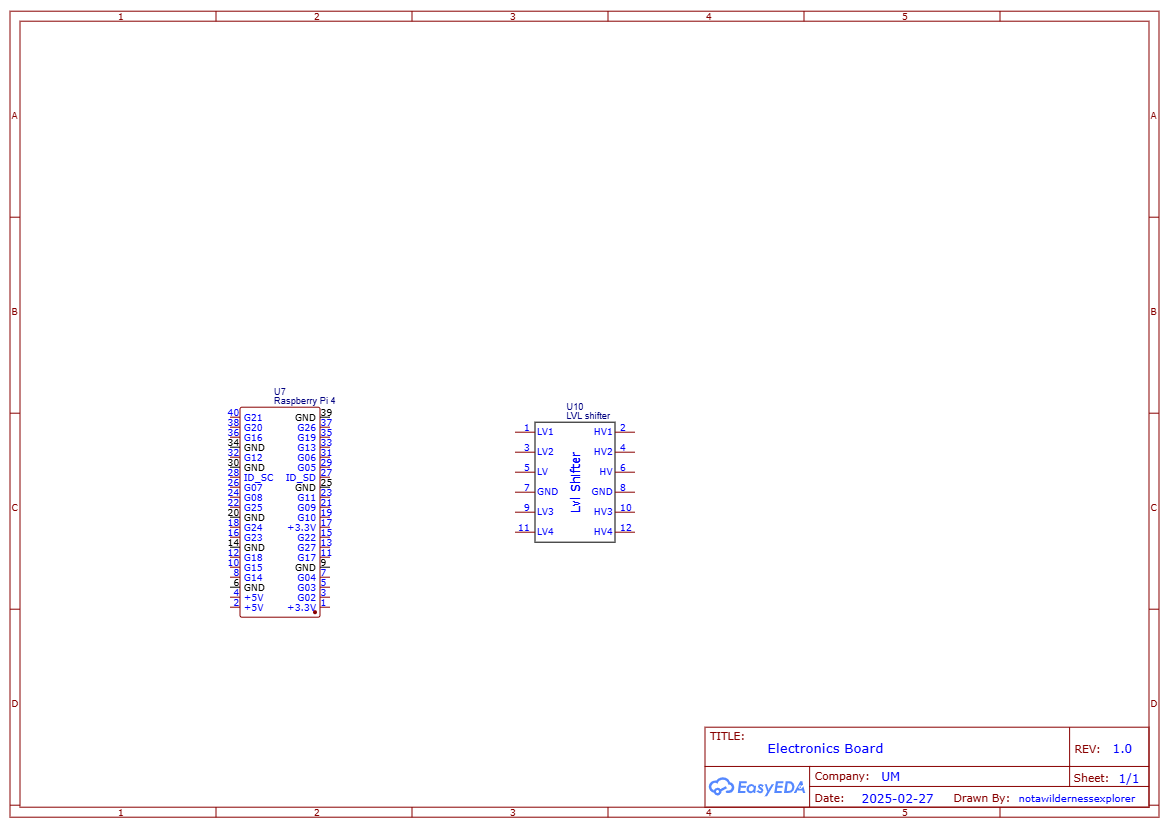
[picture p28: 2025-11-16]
embeded-low-level-electrical/2024-2025/assets/Circuits/EBoard.png

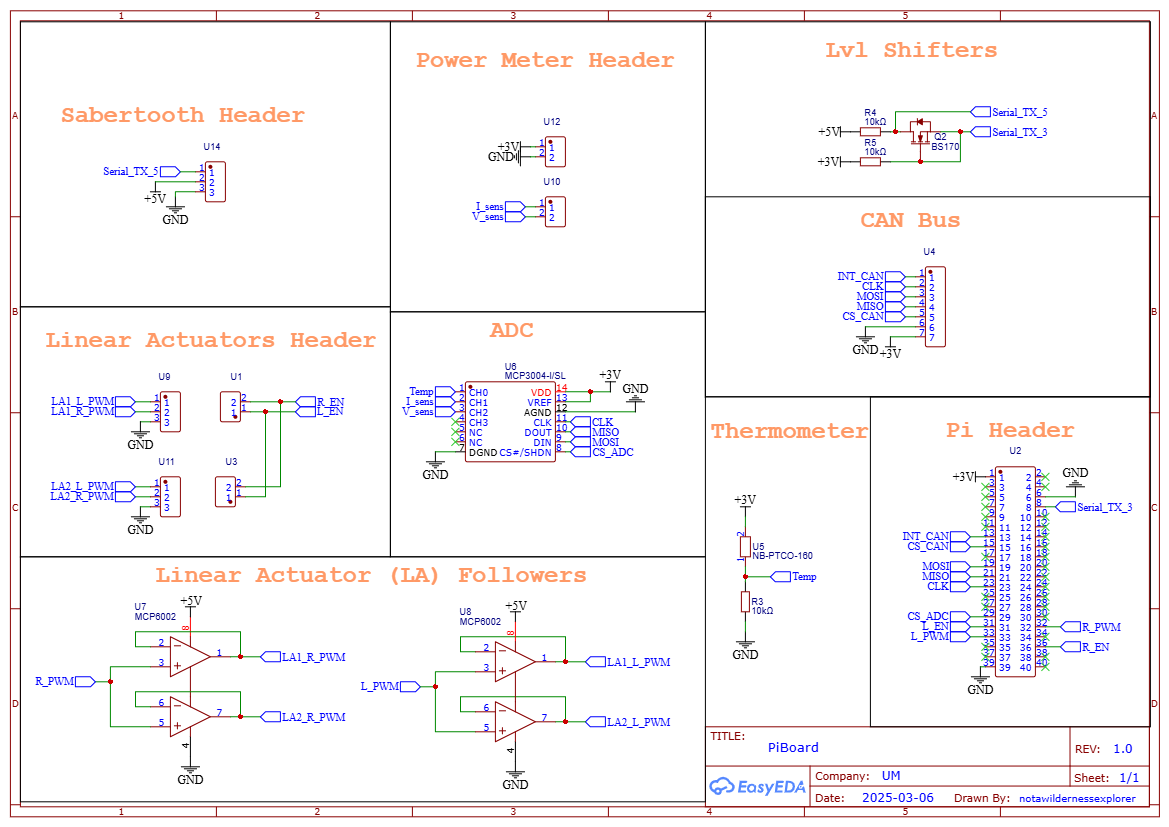
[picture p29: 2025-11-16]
embeded-low-level-electrical/2024-2025/assets/Circuits/Sheet_2.png

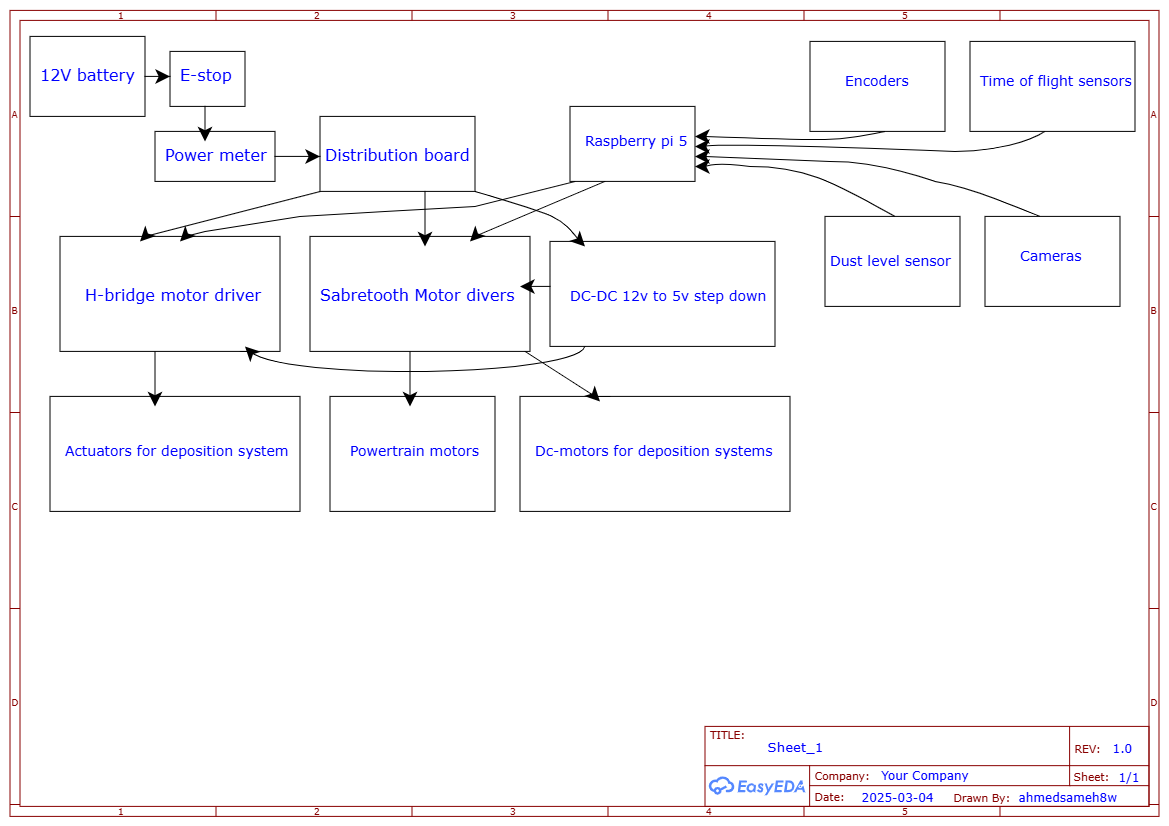
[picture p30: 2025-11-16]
embeded-low-level-electrical/2024-2025/assets/Circuits/Simple circuit.png

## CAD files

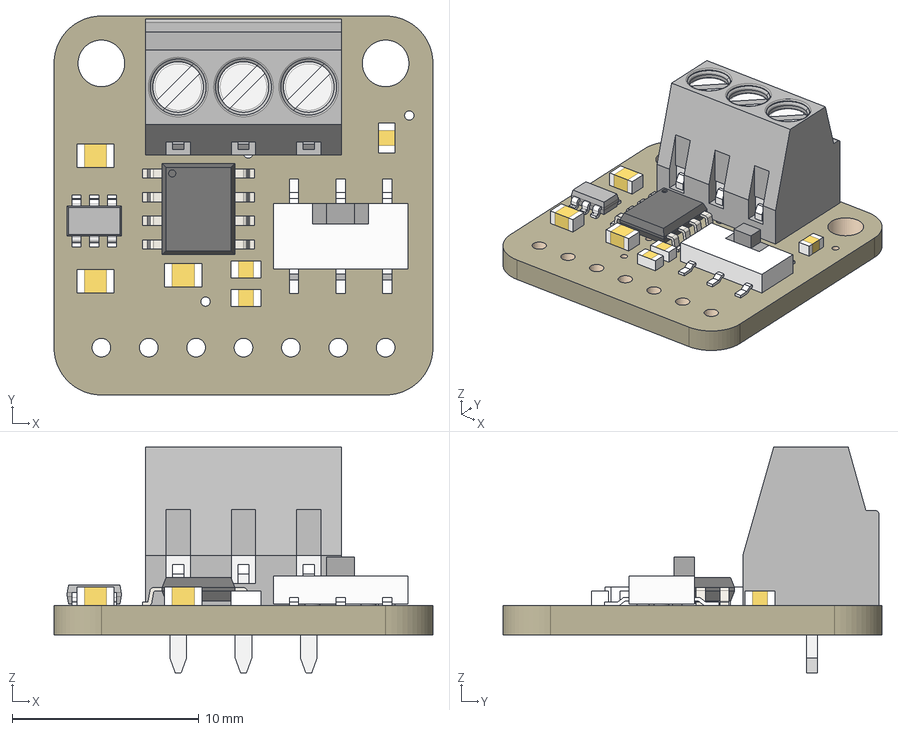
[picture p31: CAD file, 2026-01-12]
embeded-low-level-electrical/2025-2026/PCBs_schematics/ASME UM Control Board EDIT HERE/Footprint and step files/5708 CAN Pal.step
20.3 x 20.3 x 12.1 mm
Board
TJA1051T/3
3.5mm Terminal
10uF x 2
AP3602
1uF
60 ohm x 3
EG1390

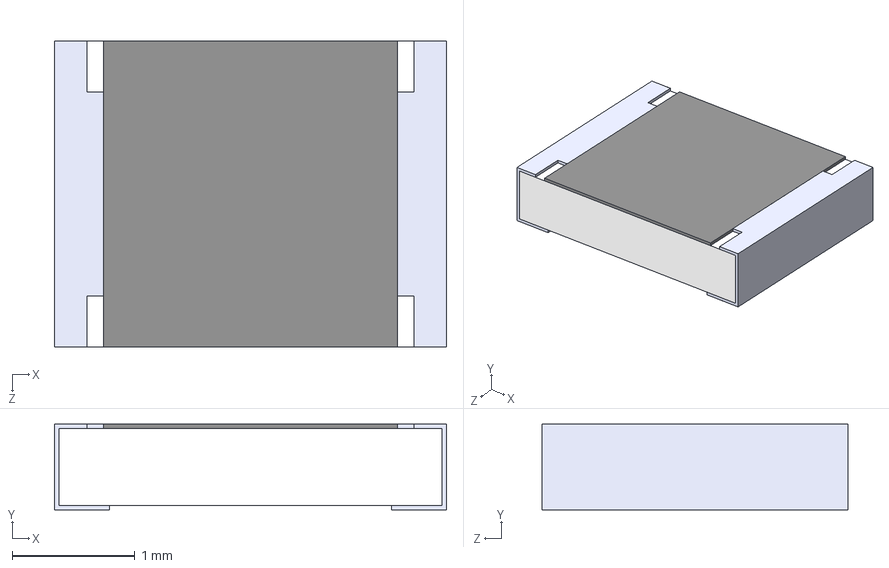
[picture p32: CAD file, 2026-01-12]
embeded-low-level-electrical/2025-2026/PCBs_schematics/ASME UM High current board EDIT HERE/Footprints/CRCW121010K0JNEAHP.step
3.20 x 0.7 x 2.50 mm

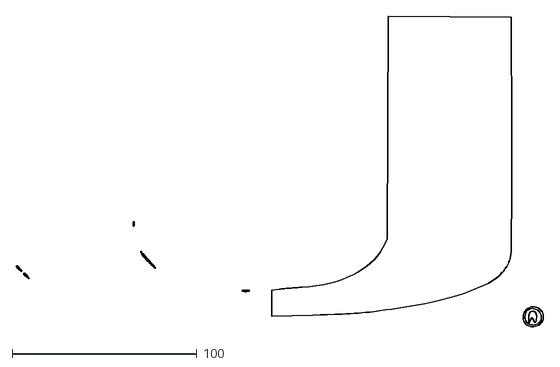
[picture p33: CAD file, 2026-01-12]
embeded-low-level-electrical/2025-2026/PCBs_schematics/ASME UM High current board EDIT HERE/Footprints/PNG/UM-logo.dxf
285.1 x 168.0

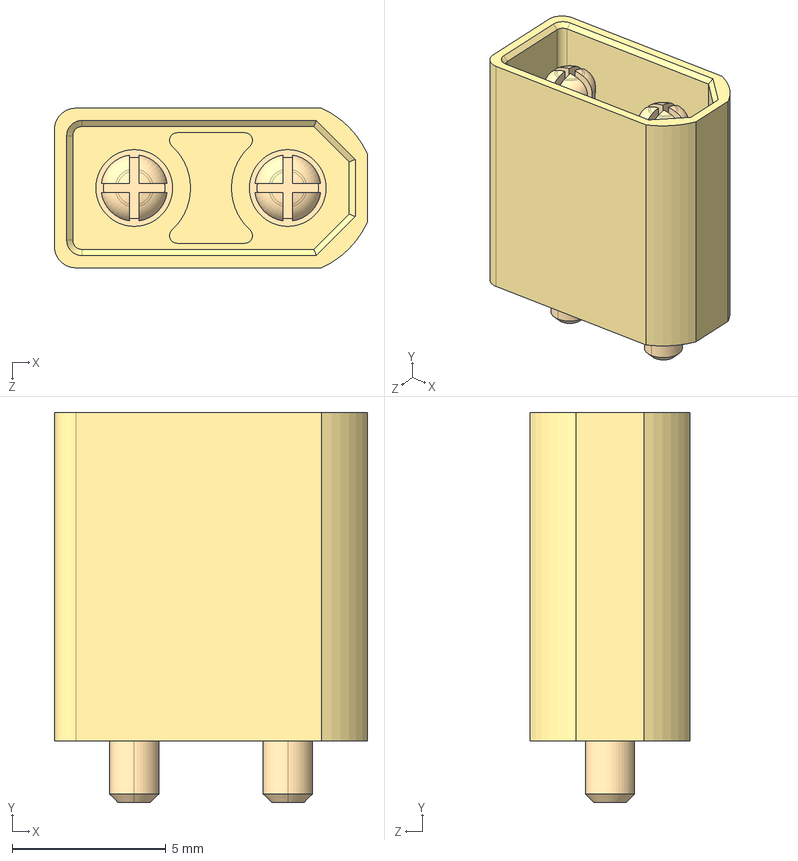
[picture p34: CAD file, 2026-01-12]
embeded-low-level-electrical/2025-2026/PCBs_schematics/ASME UM Control Board EDIT HERE/Footprint and step files/XT30UPB-M--3DModel-STEP-510211.STEP
10.2 x 12.7 x 5.20 mm

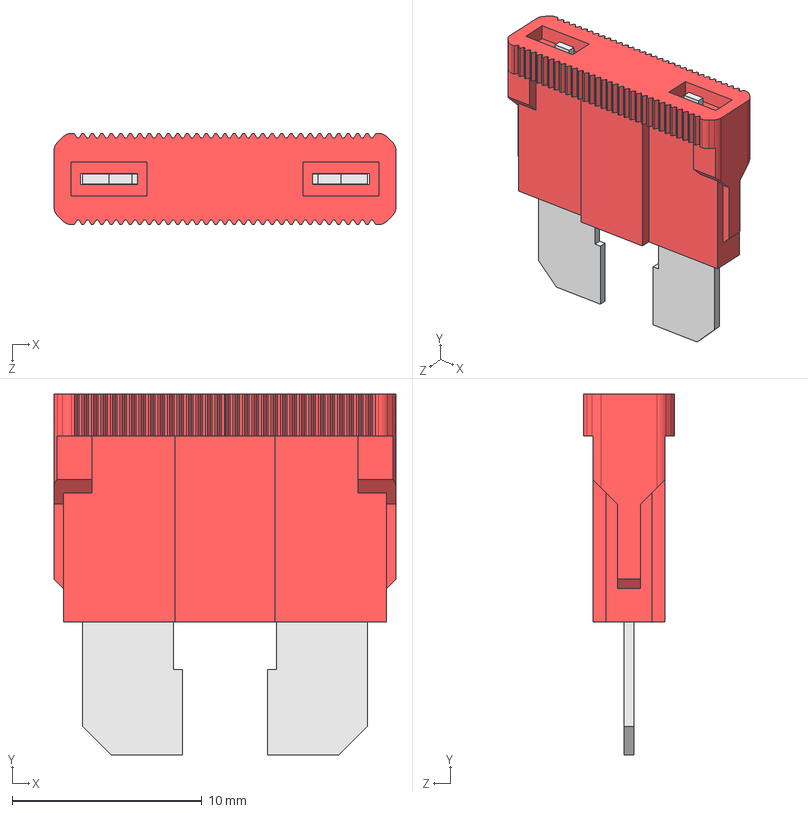
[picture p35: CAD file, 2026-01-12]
embeded-low-level-electrical/2025-2026/PCBs_schematics/ASME UM High current board EDIT HERE/Footprints/fuse-automotive-10a.STEP
18.0 x 19.0 x 4.80 mm

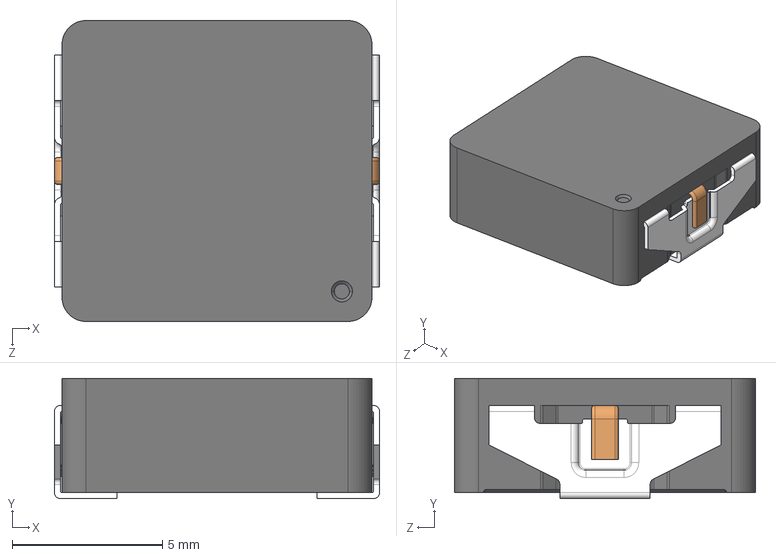
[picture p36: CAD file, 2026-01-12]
embeded-low-level-electrical/2025-2026/PCBs_schematics/ASME UM High current board EDIT HERE/Footprints/PCC-M1040M-LP(Except 1R0).step
10.8 x 4.00 x 10.0 mm

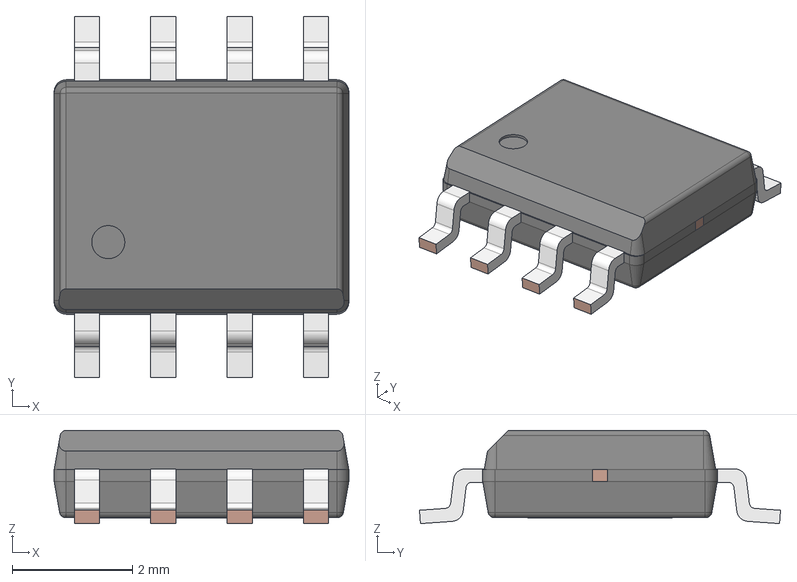
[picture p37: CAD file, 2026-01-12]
embeded-low-level-electrical/2025-2026/PCBs_schematics/ASME UM High current board EDIT HERE/Footprints/SO-8EP.STP
4.90 x 6.00 x 1.55 mm
CPD
LDF - outer lead
LDF - 8L-EP

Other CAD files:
embeded-low-level-electrical/2025-2026/PCBs_schematics/ASME UM High current board EDIT HERE/Footprints/fuse-automotive-10a.IGS
embeded-low-level-electrical/2025-2026/PCBs_schematics/ASME UM High current board EDIT HERE/Footprints/fuse-automotive-10a.SLDPRT
embeded-low-level-electrical/2025-2026/PCBs_schematics/ASME UM High current board EDIT HERE/Footprints/fuse-automotive-10a.x_b

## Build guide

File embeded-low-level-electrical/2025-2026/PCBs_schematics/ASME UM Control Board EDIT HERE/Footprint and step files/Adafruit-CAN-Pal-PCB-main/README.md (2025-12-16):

## Adafruit CAN Pal - CAN Bus Transciever - TJA1051T/3 PCB

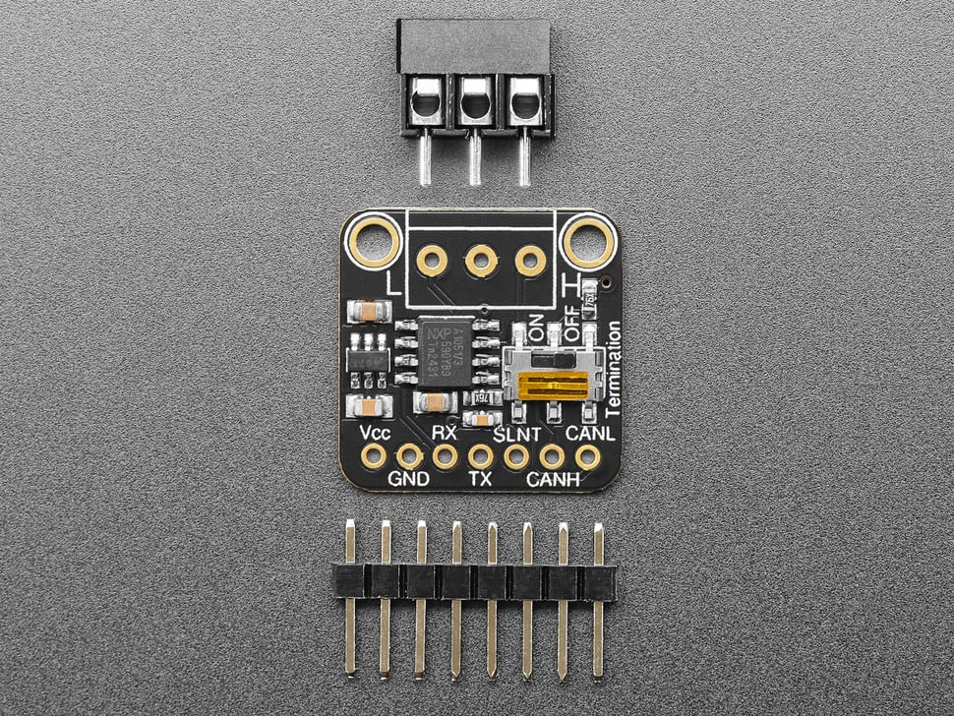
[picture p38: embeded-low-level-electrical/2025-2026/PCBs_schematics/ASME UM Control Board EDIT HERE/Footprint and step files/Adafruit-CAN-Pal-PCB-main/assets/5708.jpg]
<a href="http://www.adafruit.com/products/5708"><br/>
Click here to purchase one from the Adafruit shop</a>

PCB files for the Adafruit CAN Pal - CAN Bus Transciever - TJA1051T/3. 

Format is EagleCAD schematic and board layout
* https://www.adafruit.com/product/5708

### Description

If you'd like to connect a board with native CAN Peripheral support, the Adafruit CAN Pal Transceiver will take the 3V logic level signals and convert them to CAN logic levels with the differential signaling required to communicate. Note that not all chips have a CAN peripheral! Some that we know do have it are the ESP32/ESP32-S2/ESP32-S3 (note that ESP32 calls this interface TWAI not CAN) series of chips, SAME51, STM32F405, or Teensy 4.

Check the product documentation for the board you are wiring this to, to make sure that the chip has CAN support and the RX and TX pins are brought out for you to connect the transceiver to! Despite sharing the 'RX' and 'TX' name with UART, they're not at all the same interface.

CAN Bus is a small-scale networking standard, originally designed for cars and, yes, busses, but is now used for many robotics or sensor networks that need better range and addressing than I2C, and don't have the pins or computational ability to talk on Ethernet. CAN is 2 wire differential, which means it's good for long distances and noisy environments.

Messages are sent at about 1Mbps rate - you set the frequency for the bus and then all 'joiners' must match it, and have an address before the packet so that each node can listen in to messages just for it. New nodes can be attached easily because they just need to connect to the two data lines anywhere in the shared net. Each CAN devices sends messages whenever it wants, and thanks to some clever data encoding, can detect if there's a message collision and retransmit later. 

We've added a few nice extras to this breakout pal to make it useful in many common CAN scenarios:

* TJA1051/T3 can communicate with 3.3V~5V logic for use with modern microcontrollers. 
* 5V charge-pump voltage generator, so even though you are running 3.3V power and logic on most modern microcontroller boards, it will generate a nice clean 5V as required by the transceiver. No separate 5V power required!
* 3.5mm terminal block that can be soldered in to get quick access to the High and Low data lines as well as a ground pin.
* 2 x 60 ohm termination resistor on board (120 ohm in series), you can remove or activate the termination easily by flipping the onboard switch.

Each order comes with an assembled 'pal, terminal block and header. You will need to solder in the header yourself but its a quick task.

### License

Adafruit invests time and resources providing this open source design, please support Adafruit and open-source hardware by purchasing products from [Adafruit](https://www.adafruit.com)!

Designed by Limor Fried/Ladyada for Adafruit Industries.

Creative Commons Attribution/Share-Alike, all text above must be included in any redistribution. 
See license.txt for additional details.

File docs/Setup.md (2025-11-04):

# University of Miami　ASME Lunabotics - ROS 2 Development Environment

This guide provides step-by-step instructions for setting up and using the ROS 2 development environment for this project. This setup uses a Docker container managed by Visual Studio Code to ensure that every developer has an identical and consistent environment, eliminating "it works on my machine" issues.

---

## Prerequisites

Before you begin, ensure you have the following software installed and configured on your host machine. **Windows 11 is highly recommended**.

* **Git:** For version control.
* **WSL 2:** The Windows Subsystem for Linux. An [Ubuntu 22.04](https://ubuntu.com/wsl) distribution is recommended.
* **Docker Desktop:** Must be configured to use the **WSL 2 based engine**. You can verify this in Docker's settings: `Settings > General > Use the WSL 2 based engine`. 
* **Visual Studio Code:** The code editor.
* **VS Code Dev Containers Extension:** Search for `ms-vscode-remote.remote-containers` in the VS Code extensions panel and install it.

---

## Getting Started

Follow these steps to get the development container up and running.

### Step 1: Clone the Repository into Linux

1.  Open your WSL terminal (e.g., Ubuntu).
2.  Navigate to where you want to store your projects (e.g., your home directory).
3.  Clone the repository:

    ```bash
    git clone https://github.com/umasme/2025-2026
    ```
4.  Navigate into the project's workspace directory (the folder containing the `.devcontainer` folder).

### Step 2: Open the Project in VS Code

Launch VS Code directly from your WSL terminal within the project folder.

```bash
code .
```

### Step 3: Reopen in Container

VS Code will detect the `.devcontainer` configuration folder and display a notification in the bottom-right corner.

* Click the **"Reopen in Container"** button.

The first time you do this, VS Code will build the Docker image. This may take several minutes, as it needs to download the ROS 2 base image and install all the necessary tools. Subsequent launches will be much faster.

### Step 4: Verify Your Environment

Once the container is built and running, you can verify that everything is working correctly.

1.  **Check the Connection:** Look at the bottom-left corner of the VS Code window. It should show a green indicator with the text `Dev Container: UMASME ROS 2 Dev Container`. 
2.  **Open a Terminal:** Open a new terminal in VS Code (**Ctrl+`**). This terminal is running *inside* the container.
3.  **Add the ROS2 setup:** While in the terminal run the following commands.
     ```bash
    source /opt/ros/humble/setup.bash
    echo "source /opt/ros/humble/setup.bash" >> ~/.bashrc
    echo "source ~/ws/install/setup.bash" >> ~/.bashrc
    ```
4.  **Test a GUI Application:** Run `rviz2` to confirm that graphical applications can launch.
    ```bash
    rviz2
    ```
    The Rviz2 window should appear on your Windows desktop.

---

## Development Workflow

You are now ready to start developing!

* **Building the Workspace:** To compile your ROS 2 packages, run `colcon` from the workspace root (`/home/devuser/ws/`):
    ```bash
    colcon build --symlink-install
    ```
* **Sourcing Your Workspace:** After a successful build, remember to source your workspace to make your packages available to ROS 2. This is already added to your `.bashrc`, so it will be sourced automatically in any **new** terminal.
* **Running Your Nodes:** Use `ros2 run` to launch nodes from your packages.
    ```bash
    ros2 run your_package_name your_executable_name
    ```
* **Committing Code:** Use the **Source Control panel** in the VS Code Activity Bar on the left to stage, commit, and push your changes. This is the direct replacement for using an external tool like GitHub Desktop.

---

## Troubleshooting

### Build Fails or Runs Very Slowly

* **Problem:** The container build fails with a generic error, or the process is extremely slow.
* **Cause:** This almost always happens because the project folder is located on the Windows filesystem (e.g., `C:\Users\...`) instead of the WSL filesystem.
* **Solution:** You must move your entire project folder into WSL.
    1.  Close VS Code.
    2.  Open a WSL terminal.
    3.  Use the `mv` (move) command to relocate your project. For example, if your project is in your Windows `Documents` folder, you would run:
        ```bash
        # This command moves a folder from your Windows Documents to a 'projects' folder in WSL
        # Make sure to replace 'YourUser' and 'YourProjectFolder' with your actual folder names
        mv /mnt/c/Users/YourUser/Documents/YourProjectFolder ~/projects/
        ```
    4.  Navigate into the new project location inside WSL and relaunch VS Code with `code .`.

### Camera issues with the Intel Realsense drivers

* **Solution:** The cameras need to have a firmware version that does not contain the new hiddraw feature as this is exclusive for full Linux runs. Starting from 5.13.50 it should be fine, but it is something to have attention of.

## Notes

### Using the Intel Realsense cameras with ROS

```bash
sudo apt update && sudo apt install curl -y

sudo curl -sSL https://raw.githubusercontent.com/ros/rosdistro/master/ros.key -o /usr/share/keyrings/ros-archive-keyring.gpg

echo "deb [arch=$(dpkg --print-architecture) signed-by=/usr/share/keyrings/ros-archive-keyring.gpg] http://packages.ros.org/ros2/ubuntu $(. /etc/os-release && echo $UBUNTU_CODENAME) main" | sudo tee /etc/apt/sources.list.d/ros2.list > /dev/null

sudo apt update

sudo apt install ros-humble-desktop

source /opt/ros/humble/setup.bash

echo "source /opt/ros/humble/setup.bash" >> ~/.bashrc

sudo apt install python3-rosdep -y

sudo rosdep init

rosdep update

sudo apt install build-essential cmake git libssl-dev libusb-1.0-0-dev pkg-config libglfw3-dev

cd ~

git clone https://github.com/IntelRealSense/librealsense.git

cd librealsense

mkdir build && cd build

cmake .. -DFORCE_RSUSB_BACKEND=true -DCMAKE_BUILD_TYPE=Release -DBUILD_EXAMPLES=false -DBUILD_GRAPHICAL_EXAMPLES=false

make -j$(nproc)

sudo make install

cd ~

git clone https://github.com/umasme/2025-2026.git

cd ~/2025-2026/ws/src

git clone https://github.com/IntelRealSense/realsense-ros.git -b ros2-master

colcon build

echo "source ~/2025-2026/ws/install/setup.bash" >> ~/.bashrc

ros2 launch realsense2_camera rs_launch.py
```

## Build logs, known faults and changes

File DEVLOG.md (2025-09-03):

# 09/03/2025
Followed how-to guide from ROS to setup devcontainer. This did not work with windows. Chat recommended changing devcontainer.json file. Updated devcontainer.json file with recomended changes. ROS is working. RVIZ is not.
AM

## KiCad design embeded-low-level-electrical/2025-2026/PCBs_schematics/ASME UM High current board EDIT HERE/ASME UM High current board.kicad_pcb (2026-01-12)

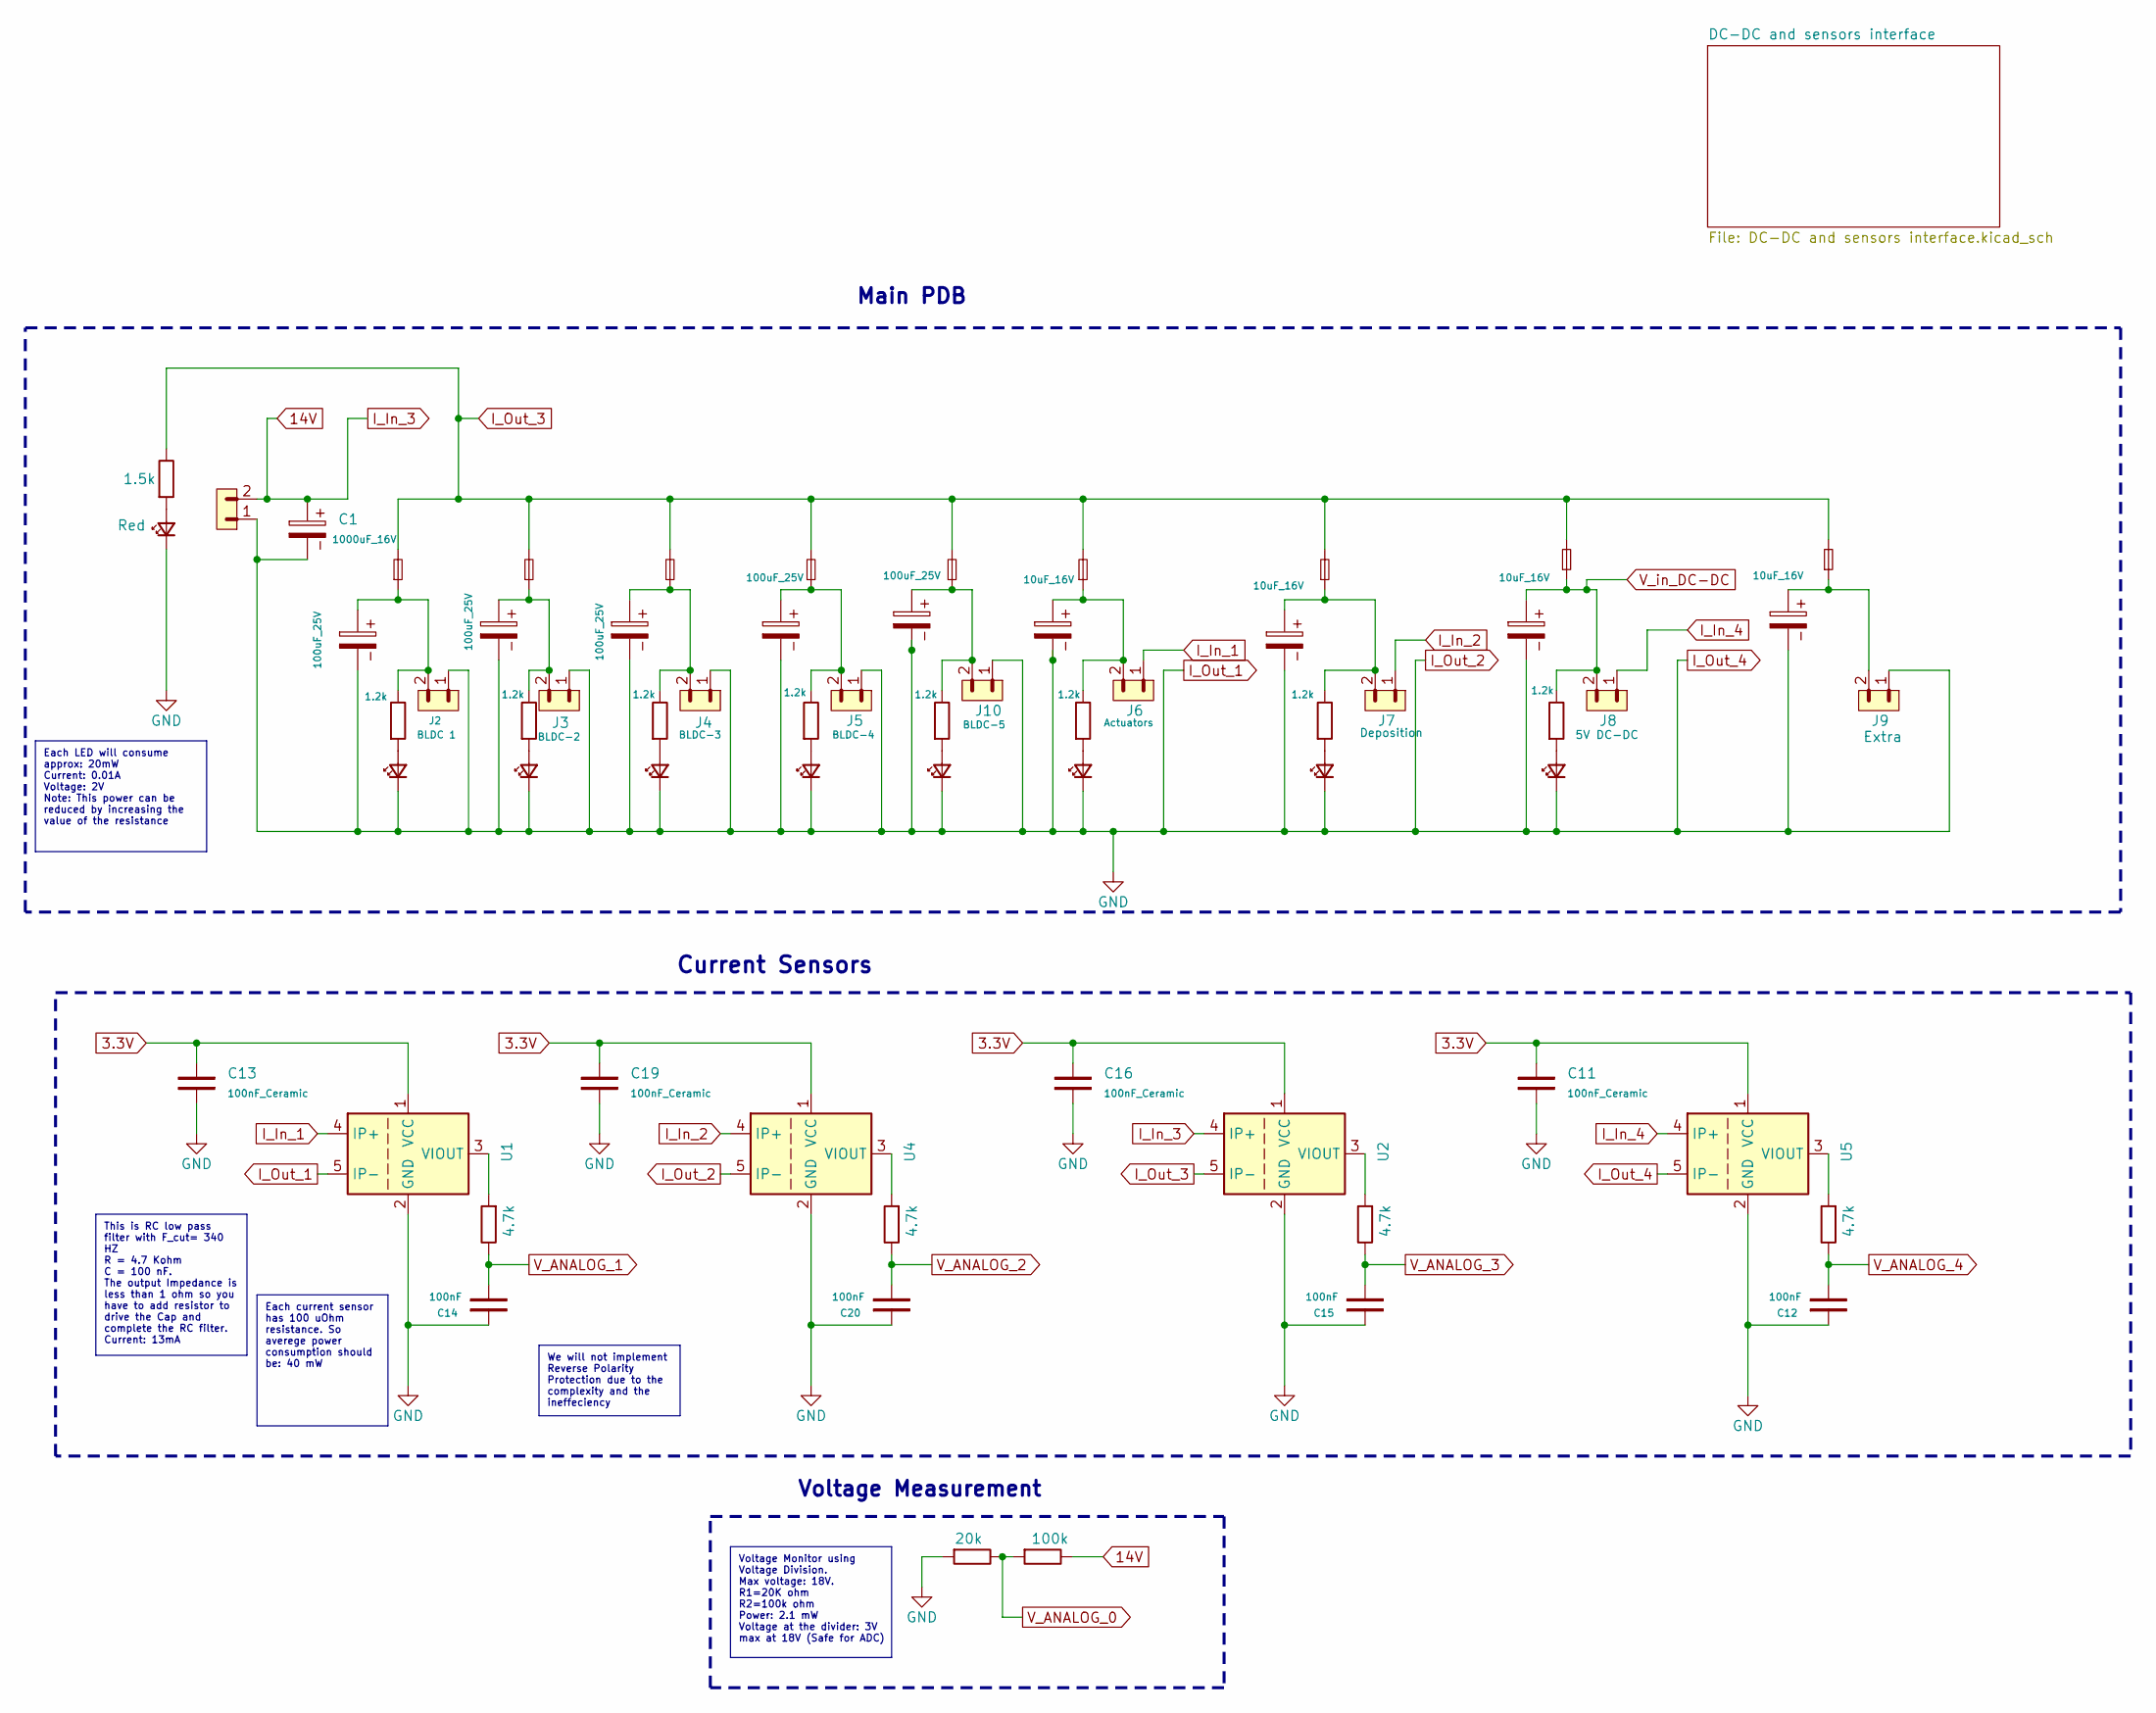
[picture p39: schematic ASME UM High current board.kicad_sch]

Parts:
C1: 1000uF_16V; CP_Radial_D10.0mm_P5.00mm
C2, C4, C5, C6: 10uF_16V; CP_Radial_D5.0mm_P2.00mm
C3, C7, C8, C9, C10: 100uF_25V; CP_Radial_D6.3mm_P2.50mm
C11, C13, C16, C19: 100nF_Ceramic; C_1206_3216Metric_Pad1.33x1.80mm_HandSolder
C12, C14, C15, C20: 100nF; C_1206_3216Metric_Pad1.33x1.80mm_HandSolder
D1: Red; LED_1206_3216Metric_Red
D2, D3, D4, D5, D6, D7, D8, D9: Green; LED_1206_3216Metric_Green
F1, F2, F3, F4, F5, F6, F7, F8, F9: Blade Fuse; Fuseholder_Automotive
J1: From main battery; AMASS_XT60-M_1x02_P7.20mm_Vertical
J2: BLDC 1; AMASS_XT60-M_1x02_P7.20mm_Vertical
J3: BLDC-2; AMASS_XT60-M_1x02_P7.20mm_Vertical
J4: BLDC-3; AMASS_XT60-M_1x02_P7.20mm_Vertical
J5: BLDC-4; AMASS_XT60-M_1x02_P7.20mm_Vertical
J6: Actuators; AMASS_XT60-M_1x02_P7.20mm_Vertical
J7: Deposition; AMASS_XT60-M_1x02_P7.20mm_Vertical
J8: 5V DC-DC; AMASS_XT60-M_1x02_P7.20mm_Vertical
J9: Extra; AMASS_XT60-M_1x02_P7.20mm_Vertical
J10: BLDC-5; AMASS_XT60-M_1x02_P7.20mm_Vertical
R1: 1.5k; R_1206_3216Metric_Pad1.30x1.75mm_HandSolder
R2, R3, R4, R5, R6, R7, R8, R9: 1.2k; R_1206_3216Metric_Pad1.30x1.75mm_HandSolder
R11, R12, R13, R16: 4.7k; R_1206_3216Metric_Pad1.30x1.75mm_HandSolder
R14: 20k; R_1206_3216Metric_Pad1.30x1.75mm_HandSolder
R15: 100k; R_1206_3216Metric_Pad1.30x1.75mm_HandSolder
U1, U4, U5: ACS758xCB-050B-PFF; Allegro_CB_PFF
U2: ACS772xCB-050B-PFF; Allegro_CB_PFF

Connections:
3.3V: C11.1, C13.1, C16.1, C19.1, U1.1 (VCC), U2.1 (VCC), U4.1 (VCC), U5.1 (VCC); also elsewhere on the board
14V: C1.1, J1.2, R15.2, U2.4 (IP+); also elsewhere on the board
I_In_1: J6.1, U1.4 (IP+)
I_In_2: J7.1, U4.4 (IP+)
I_In_4: J8.1, U5.4 (IP+); also elsewhere on the board
I_Out_1: C1.2, C2.2, C3.2, C4.2, C5.2, C6.2, C7.2, C8.2, C9.2, C10.2, C11.2, C12.1, C13.2, C14.1, C15.1, C16.2, C19.2, C20.1, D1.1 (K), D2.1 (K), D3.1 (K), D4.1 (K), D5.1 (K), D6.1 (K), D7.1 (K), D8.1 (K), D9.1 (K), J1.1, J2.1, J3.1, J4.1, J5.1, J9.1, J10.1, R14.1, U1.2 (GND), U1.5 (IP-), U2.2 (GND), U4.2 (GND), U4.5 (IP-), U5.2 (GND), U5.5 (IP-); also elsewhere on the board
I_Out_3: F1.2, F2.2, F3.2, F4.2, F5.2, F6.2, F7.2, F8.2, F9.2, R1.2, U2.5 (IP-)
unnamed: C2.1, F9.1, J9.2
unnamed: C3.1, F1.1, J2.2, R2.2
unnamed: C5.1, F7.1, J7.2, R7.2
unnamed: C6.1, F6.1, J6.2, R8.2
unnamed: C7.1, F4.1, J5.2, R5.2
unnamed: C8.1, F3.1, J4.2, R4.2
unnamed: C9.1, F2.1, J3.2, R3.2
unnamed: C10.1, F5.1, J10.2, R6.2
unnamed: D1.2 (A), R1.1
unnamed: D2.2 (A), R2.1
unnamed: D3.2 (A), R3.1
unnamed: D4.2 (A), R4.1
unnamed: D5.2 (A), R5.1
unnamed: D6.2 (A), R6.1
unnamed: D7.2 (A), R8.1
unnamed: D8.2 (A), R7.1
unnamed: D9.2 (A), R9.1
unnamed: R12.1, U1.3 (VIOUT)
unnamed: R13.1, U2.3 (VIOUT)
unnamed: R16.1, U4.3 (VIOUT)
unnamed: R11.1, U5.3 (VIOUT)
V_ANALOG_0: R14.2, R15.1; also elsewhere on the board
V_ANALOG_1: C14.2, R12.2; also elsewhere on the board
V_ANALOG_2: C20.2, R16.2; also elsewhere on the board
V_ANALOG_3: C15.2, R13.2; also elsewhere on the board
V_ANALOG_4: C12.2, R11.2; also elsewhere on the board
V_in_DC-DC: C4.1, F8.1, J8.2, R9.2; also elsewhere on the board

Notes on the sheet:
Current Sensors
Main PDB
Voltage Measurement
Voltage Monitor using Voltage Division. Max voltage: 18V. R1=20K ohm R2=100k ohm Power: 2.1 mW Voltage at the divider: 3V max at 18V (Safe for ADC)
Each LED will consume approx: 20mW Current: 0.01A Voltage: 2V Note: This power can be reduced by increasing the value of the resistance
We will not implement Reverse Polarity Protection due to the complexity and the ineffeciency
Each current sensor has 100 uOhm resistance. So averege power consumption should be: 40 mW
This is RC low pass filter with F_cut= 340 HZ R = 4.7 Kohm C = 100 nF. The output Impedance is less than 1 ohm so you have to add resistor to drive the Cap and complete the RC filter. Current: 13mA

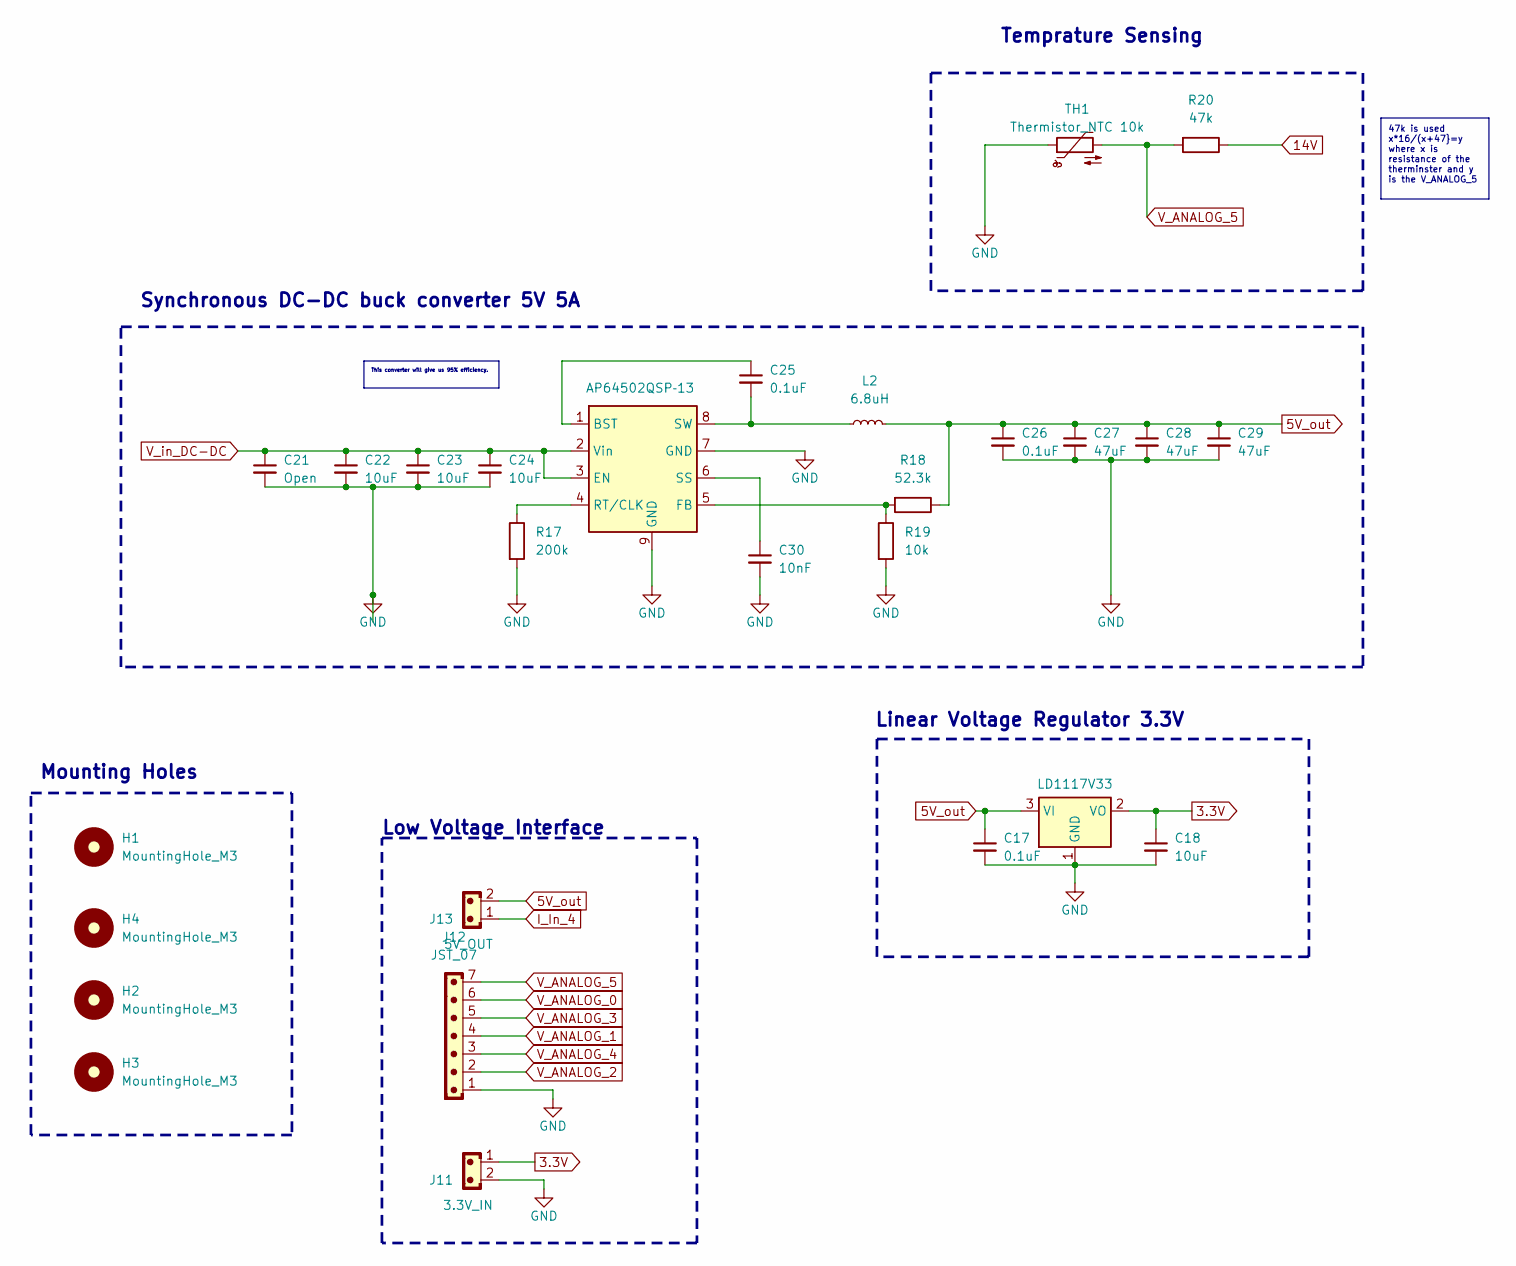
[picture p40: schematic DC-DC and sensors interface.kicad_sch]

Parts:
C17, C25, C26: 0.1uF; C_1206_3216Metric_Pad1.33x1.80mm_HandSolder; Voltage 25V; Tolerance 20%
C18: 10uF; CP_Radial_D5.0mm_P2.00mm; Voltage 25V; Tolerance 20%
C21: Open; C_1206_3216Metric_Pad1.33x1.80mm_HandSolder; Voltage 25V; Tolerance 20%
C22, C23, C24: 10uF; C_1206_3216Metric_Pad1.33x1.80mm_HandSolder; Voltage 25V; Tolerance 20%
C27, C28, C29: 47uF; C_1206_3216Metric_Pad1.33x1.80mm_HandSolder; Voltage 25V; Tolerance 20%
C30: 10nF; C_1206_3216Metric_Pad1.33x1.80mm_HandSolder; Voltage 25V; Tolerance 20%
H1, H2, H3, H4: MountingHole_M3; MountingHole_3.2mm_M3_DIN965_Pad_TopBottom
J11: 3.3V_IN; JST_EH_B2B-EH-A_1x02_P2.50mm_Vertical
J12: JST_07; JST_EH_B7B-EH-A_1x07_P2.50mm_Vertical
J13: 5V_OUT; AMASS_XT30U-M_1x02_P5.0mm_Vertical
L2: 6.8uH; IND_PCC-M1040LP_PAN-M
R17: 200k; R_1206_3216Metric_Pad1.30x1.75mm_HandSolder
R18: 52.3k; R_1206_3216Metric_Pad1.30x1.75mm_HandSolder
R19: 10k; R_1206_3216Metric_Pad1.30x1.75mm_HandSolder
R20: 47k; R_1206_3216Metric_Pad1.30x1.75mm_HandSolder
TH1: Thermistor_NTC 10k; 1210
U3: LD1117V33; TO-220-3_Vertical
U7: AP64502QSP‑13; Diodes_SO-8EP

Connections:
3.3V: C18.1, J11.1, U3.2 (VO); also elsewhere on the board
5V_out: C17.1, C26.1, C27.1, C28.1, C29.1, J13.2, L2.2, R18.1, U3.3 (VI)
14V: R20.1; also elsewhere on the board
I_In_4: J13.1; also elsewhere on the board
I_Out_1: C17.2, C18.2, C21.2, C22.2, C23.2, C24.2, C26.2, C27.2, C28.2, C29.2, C30.2, J11.2, J12.1, R17.2, R19.2, TH1.1, U3.1 (GND), U7.7 (GND), U7.9 (GND); also elsewhere on the board
unnamed: C25.1, U7.1 (BST)
unnamed: R18.2, R19.1, U7.5 (FB)
unnamed: R17.1, U7.4 (RT/CLK)
unnamed: C30.1, U7.6 (SS)
unnamed: C25.2, L2.1, U7.8 (SW)
V_ANALOG_0: J12.6; also elsewhere on the board
V_ANALOG_1: J12.4; also elsewhere on the board
V_ANALOG_2: J12.2; also elsewhere on the board
V_ANALOG_3: J12.5; also elsewhere on the board
V_ANALOG_4: J12.3; also elsewhere on the board
V_ANALOG_5: J12.7, R20.2, TH1.2
V_in_DC-DC: C21.1, C22.1, C23.1, C24.1, U7.2 (Vin), U7.3 (EN); also elsewhere on the board

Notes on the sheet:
Synchronous DC-DC buck converter 5V 5A
Mounting Holes
Temprature Sensing
Low Voltage Interface
Linear Voltage Regulator 3.3V
This converter will give us 95% efficiency.
47k is used x*16/(x+47}=y where x is resistance of the therminster and y is the V_ANALOG_5

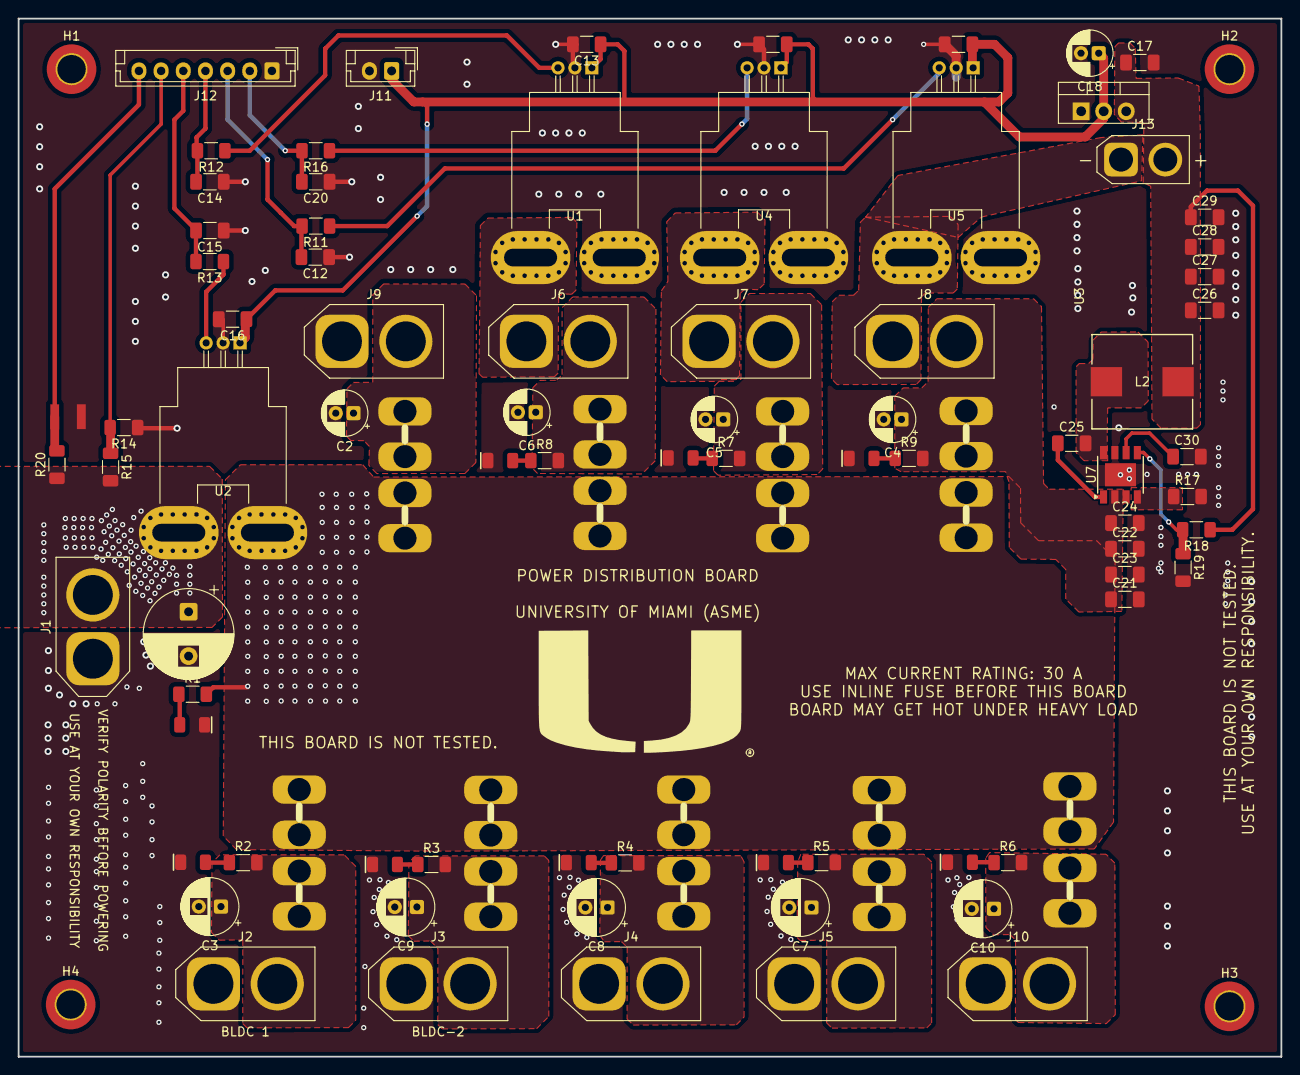
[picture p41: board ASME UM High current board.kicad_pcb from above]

Board: 2 copper layers, 142.4 x 117.1 mm, 92 parts (0 on the bottom side), 41 nets.

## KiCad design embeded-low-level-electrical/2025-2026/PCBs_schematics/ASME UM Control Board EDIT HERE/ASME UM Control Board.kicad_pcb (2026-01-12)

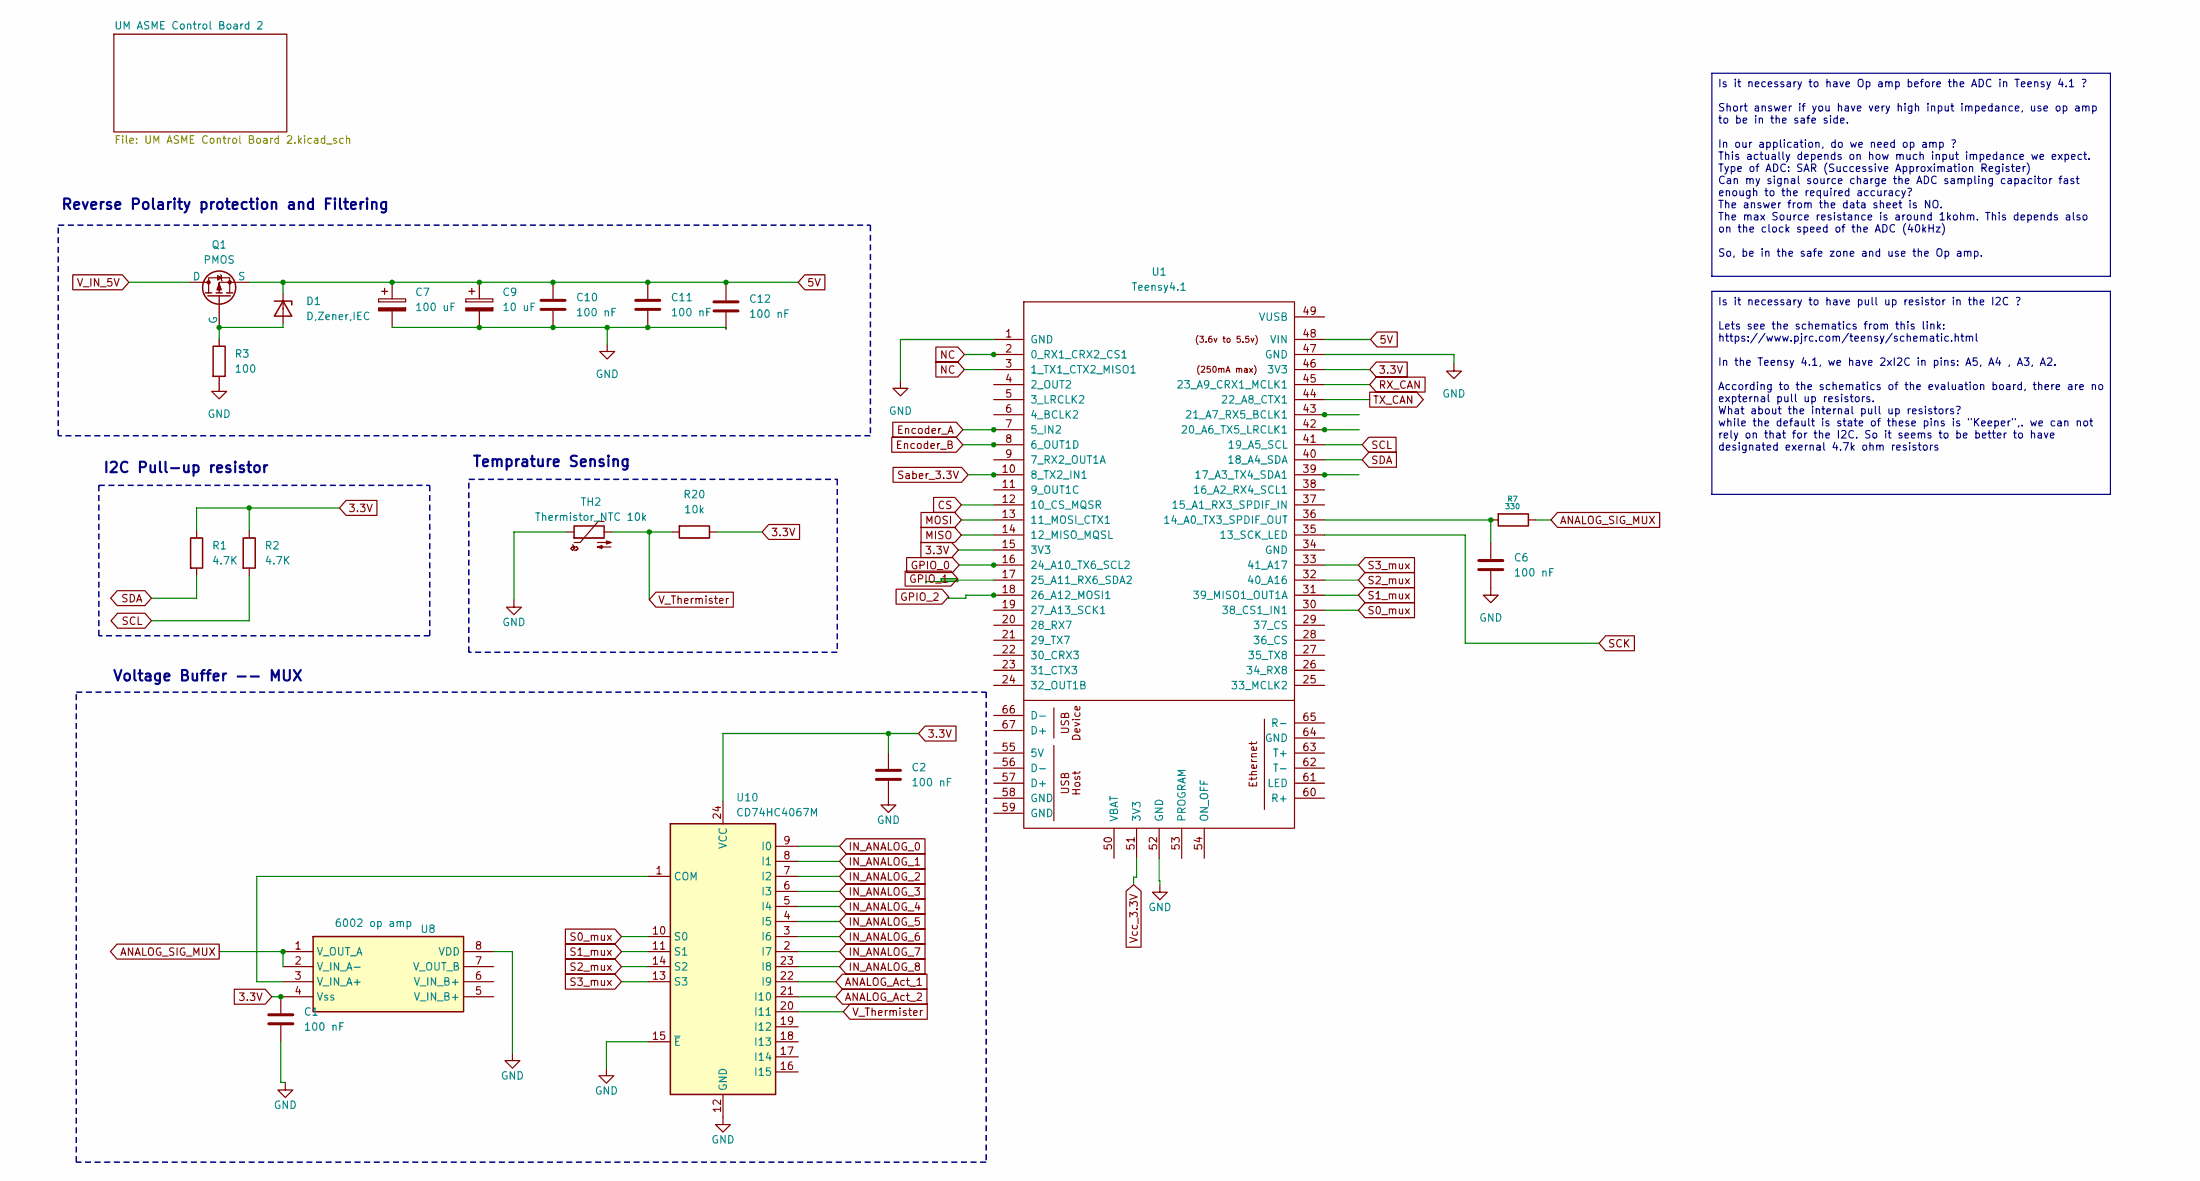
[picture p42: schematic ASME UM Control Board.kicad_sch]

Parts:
C1, C2, C6, C10, C11, C12: 100 nF; C_1206_3216Metric_Pad1.33x1.80mm_HandSolder
C7: 100 uF; CP_Radial_D8.0mm_P2.50mm
C9: 10 uF; C_1206_3216Metric_Pad1.33x1.80mm_HandSolder
D1: D,Zener,IEC; D_DO-35_SOD27_P7.62mm_Horizontal
Q1: PMOS; TO-220-3_Vertical
R1, R2: 4.7K; R_1206_3216Metric_Pad1.30x1.75mm_HandSolder
R3: 100; R_1206_3216Metric_Pad1.30x1.75mm_HandSolder
R7: 330; R_1206_3216Metric_Pad1.30x1.75mm_HandSolder
R20: 10k; R_1206_3216Metric_Pad1.30x1.75mm_HandSolder
TH2: Thermistor_NTC 10k; 1210
U1: Teensy4.1; Teensy41
U8: 6002 op amp; DIP-8_W7.62mm_LongPads
U10: CD74HC4067M; SOIC-24W_7.5x15.4mm_P1.27mm

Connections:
3.3V: C1.1, C2.1, R1.1, R2.1, R20.1, U1.15 (3V3), U1.46 (3V3), U8.4 (Vss), U10.24 (VCC); also elsewhere on the board
5V: C7.1, C9.1, C10.1, C11.1, C12.1, D1.1 (K-), Q1.3 (S), U1.48 (VIN); also elsewhere on the board
ANALOG_Act_1: U10.22 (I9); also elsewhere on the board
ANALOG_Act_2: U10.21 (I10); also elsewhere on the board
ANALOG_SIG_MUX: R7.1, U8.1 (V_OUT_A), U8.2 (V_IN_A-)
CS: U1.12 (10_CS_MQSR)
Encoder_A: U1.7 (5_IN2); also elsewhere on the board
Encoder_B: U1.8 (6_OUT1D); also elsewhere on the board
GND: C1.2, C2.2, C6.2, C7.2, C9.2, C10.2, C11.2, C12.2, R3.2, TH2.1, U1.1 (GND), U1.47 (GND), U1.52 (GND), U8.8 (VDD), U10.12 (GND), U10.15 (~E); also elsewhere on the board
GPIO_0: U1.16 (24_A10_TX6_SCL2); also elsewhere on the board
GPIO_1: U1.17 (25_A11_RX6_SDA2); also elsewhere on the board
GPIO_2: U1.18 (26_A12_MOSI1); also elsewhere on the board
IN_ANALOG_0: U10.9 (I0); also elsewhere on the board
IN_ANALOG_1: U10.8 (I1); also elsewhere on the board
IN_ANALOG_2: U10.7 (I2); also elsewhere on the board
IN_ANALOG_3: U10.6 (I3); also elsewhere on the board
IN_ANALOG_4: U10.5 (I4); also elsewhere on the board
IN_ANALOG_5: U10.4 (I5); also elsewhere on the board
IN_ANALOG_6: U10.3 (I6); also elsewhere on the board
IN_ANALOG_7: U10.2 (I7); also elsewhere on the board
IN_ANALOG_8: U10.23 (I8); also elsewhere on the board
MISO: U1.14 (12_MISO_MQSL)
MOSI: U1.13 (11_MOSI_CTX1)
NC: U1.2 (0_RX1_CRX2_CS1), U1.3 (1_TX1_CTX2_MISO1)
unnamed: D1.2 (A+), Q1.2 (G), R3.1
unnamed: C6.1, R7.2, U1.36 (14_A0_TX3_SPDIF_OUT)
unnamed: U8.3 (V_IN_A+), U10.1 (COM)
RX_CAN: U1.45 (23_A9_CRX1_MCLK1); also elsewhere on the board
S0_mux: U1.30 (38_CS1_IN1), U10.10 (S0)
S1_mux: U1.31 (39_MISO1_OUT1A), U10.11 (S1)
S2_mux: U1.32 (40_A16), U10.14 (S2)
S3_mux: U1.33 (41_A17), U10.13 (S3)
SCK: U1.35 (13_SCK_LED)
SCL: R2.2, U1.41 (19_A5_SCL); also elsewhere on the board
SDA: R1.2, U1.40 (18_A4_SDA); also elsewhere on the board
Saber_3.3V: U1.10 (8_TX2_IN1); also elsewhere on the board
TX_CAN: U1.44 (22_A8_CTX1); also elsewhere on the board
V_IN_5V: Q1.1 (D); also elsewhere on the board
V_Thermister: R20.2, TH2.2, U10.20 (I11)

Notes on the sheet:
Voltage Buffer -- MUX
Temprature Sensing
Reverse Polarity protection and Filtering
I2C Pull-up resistor
Is it necessary to have Op amp before the ADC in Teensy 4.1 ? Short answer if you have very high input impedance, use op amp to be in the safe side. In our application, do we need op amp ? This actually depends on how much input impedance we expect. Type of ADC: SAR (Successive Approximation Regist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
Is it necessary to have pull up resistor in the I2C ? Lets see the schematics from this link: https://www.pjrc.com/teensy/schematic.html In the Teensy 4.1, we have 2xI2C in pins: A5, A4 , A3, A2. According to the schematics of the evaluation board, there are no expternal pull up resistors. What abo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

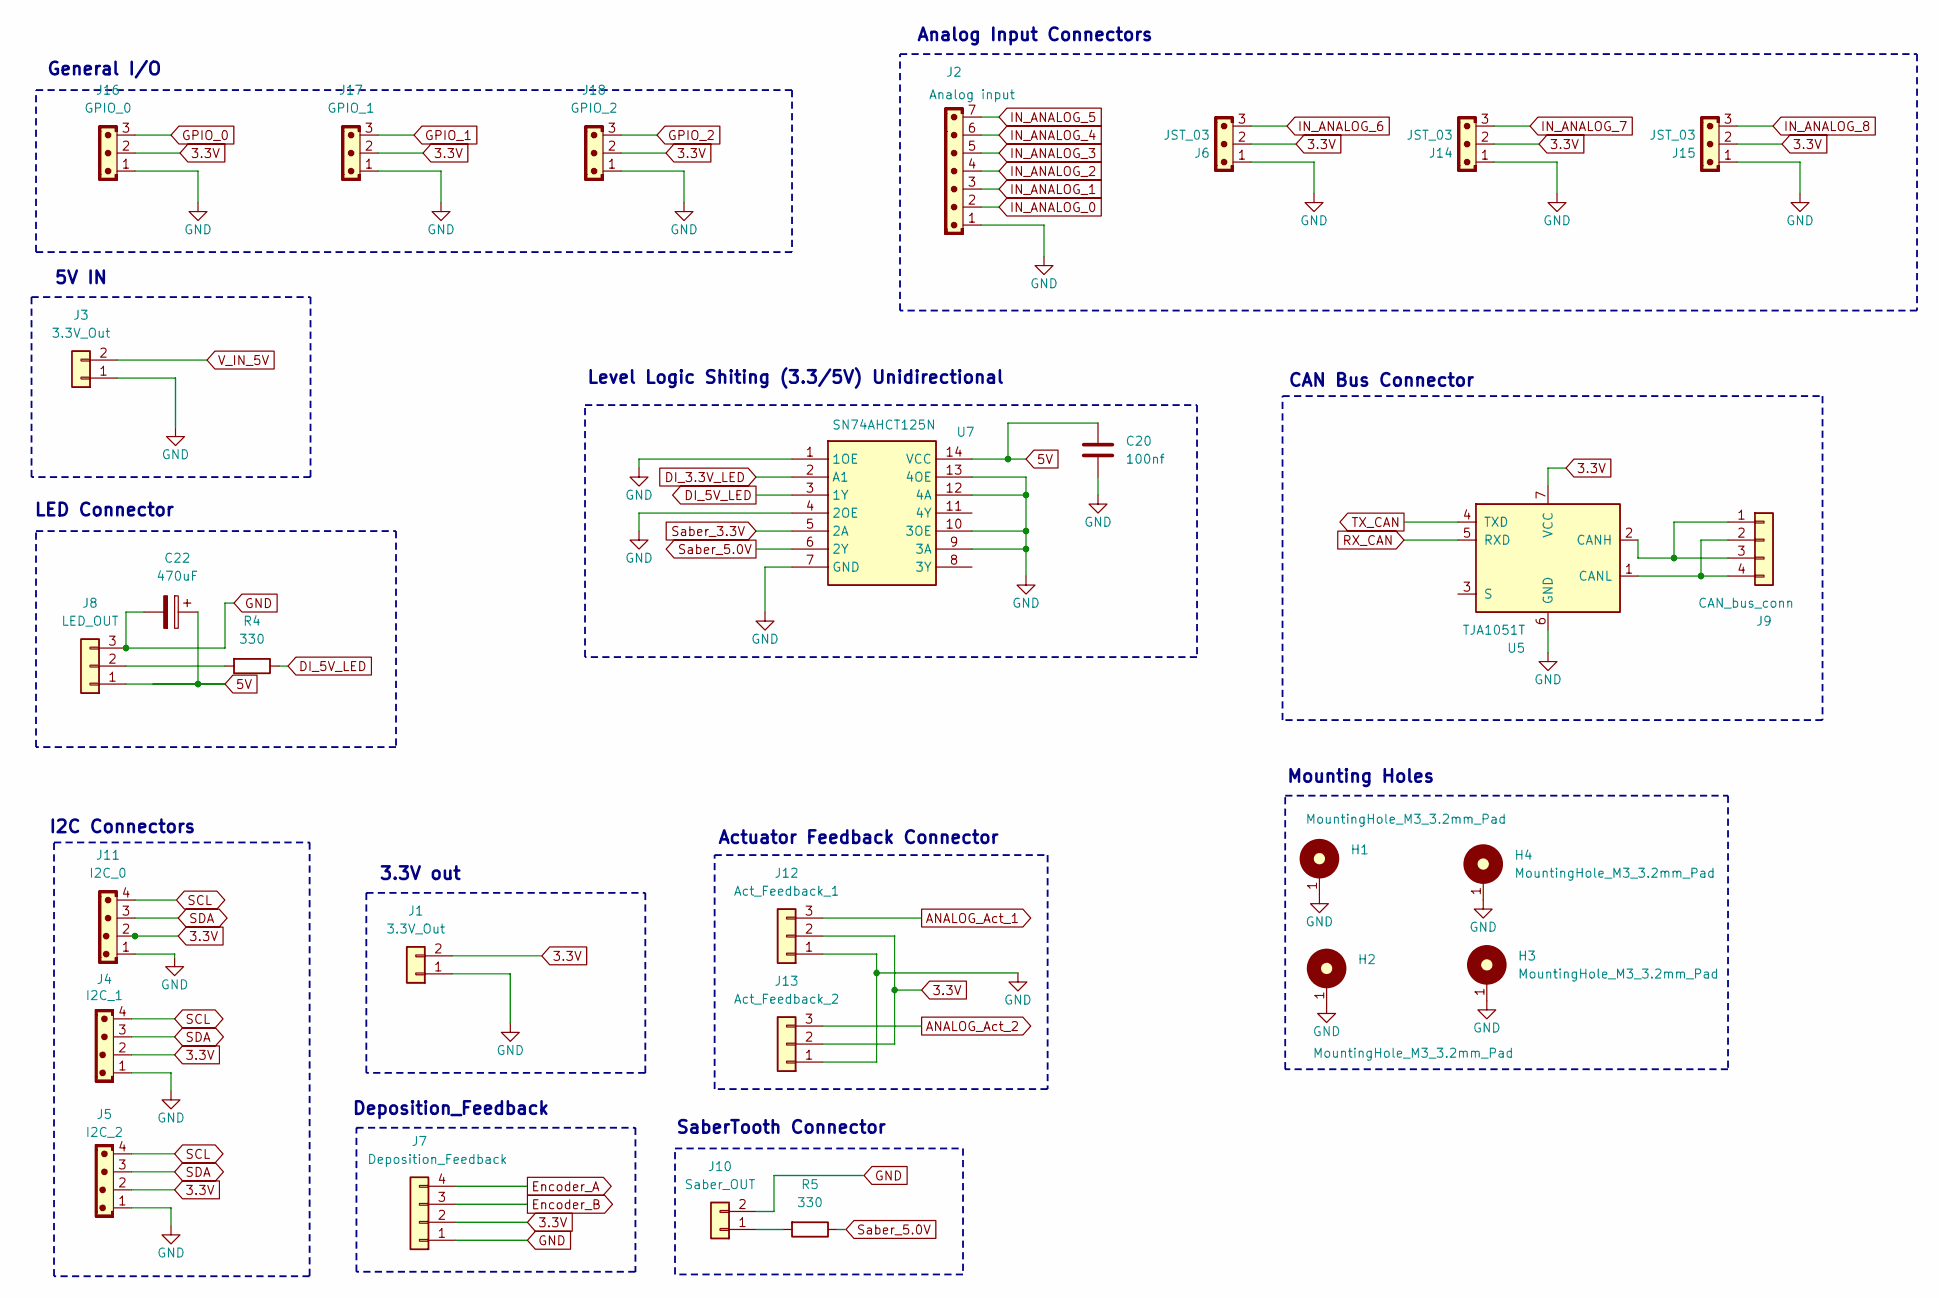
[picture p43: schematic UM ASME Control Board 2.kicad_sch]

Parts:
C20: 100nf; C_1206_3216Metric_Pad1.33x1.80mm_HandSolder
C22: 470uF; CP_Radial_D10.0mm_P3.80mm
H1, H2, H3, H4: MountingHole_M3_3.2mm_Pad; MountingHole_3.2mm_Pad
J1: 3.3V_Out; JST_PH_B2B-PH-K_1x02_P2.00mm_Vertical
J2: Analog input; JST_PH_B7B-PH-K_1x07_P2.00mm_Vertical
J3: 3.3V_Out; AMASS_XT30UPB-M_1x02_P5.0mm_Vertical
J4: I2C_1; JST_PH_B4B-PH-K_1x04_P2.00mm_Vertical
J5: I2C_2; JST_PH_B4B-PH-K_1x04_P2.00mm_Vertical
J6, J14, J15: JST_03; JST_PH_B3B-PH-K_1x03_P2.00mm_Vertical
J7: Deposition_Feedback; JST_PH_B4B-PH-K_1x04_P2.00mm_Vertical
J8: LED_OUT; JST_EH_B3B-EH-A_1x03_P2.50mm_Vertical
J9: CAN_bus_conn; JST_PH_B4B-PH-K_1x04_P2.00mm_Vertical
J10: Saber_OUT; JST_PH_B2B-PH-K_1x02_P2.00mm_Vertical
J11: I2C_0; JST_PH_B4B-PH-K_1x04_P2.00mm_Vertical
J12: Act_Feedback_1; JST_PH_B3B-PH-K_1x03_P2.00mm_Vertical
J13: Act_Feedback_2; JST_PH_B3B-PH-K_1x03_P2.00mm_Vertical
J16: GPIO_0; JST_PH_B3B-PH-K_1x03_P2.00mm_Vertical
J17: GPIO_1; JST_PH_B3B-PH-K_1x03_P2.00mm_Vertical
J18: GPIO_2; JST_PH_B3B-PH-K_1x03_P2.00mm_Vertical
R4, R5: 330; R_1206_3216Metric_Pad1.30x1.75mm_HandSolder
U5: TJA1051T; PinHeader_1x07_P2.54mm_Vertical
U7: SN74AHCT125N; DIP-14_W7.62mm_LongPads

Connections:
3.3V: J1.2, J4.2, J5.2, J6.2, J7.2, J11.2, J12.2, J13.2, J14.2, J15.2, J16.2, J17.2, J18.2, U5.7 (VCC); also elsewhere on the board
5V: C20.2, C22.1, J8.1, U7.14 (VCC); also elsewhere on the board
ANALOG_Act_1: J12.3; also elsewhere on the board
ANALOG_Act_2: J13.3; also elsewhere on the board
DI_3.3V_LED: U7.2 (A1)
DI_5V_LED: R4.1, U7.3 (1Y)
Encoder_A: J7.4; also elsewhere on the board
Encoder_B: J7.3; also elsewhere on the board
GND: C20.1, C22.2, H1.1, H2.1, H3.1, H4.1, J1.1, J2.1, J3.1, J4.1, J5.1, J6.1, J7.1, J8.3, J10.2, J11.1, J12.1, J13.1, J14.1, J15.1, J16.1, J17.1, J18.1, U5.6 (GND), U7.1 (1OE), U7.4 (2OE), U7.7 (GND), U7.9 (3A), U7.10 (3OE), U7.12 (4A), U7.13 (4OE); also elsewhere on the board
GPIO_0: J16.3; also elsewhere on the board
GPIO_1: J17.3; also elsewhere on the board
GPIO_2: J18.3; also elsewhere on the board
IN_ANALOG_0: J2.2; also elsewhere on the board
IN_ANALOG_1: J2.3; also elsewhere on the board
IN_ANALOG_2: J2.4; also elsewhere on the board
IN_ANALOG_3: J2.5; also elsewhere on the board
IN_ANALOG_4: J2.6; also elsewhere on the board
IN_ANALOG_5: J2.7; also elsewhere on the board
IN_ANALOG_6: J6.3; also elsewhere on the board
IN_ANALOG_7: J14.3; also elsewhere on the board
IN_ANALOG_8: J15.3; also elsewhere on the board
unnamed: J8.2, R4.2
unnamed: J9.1, J9.3, U5.2 (CANH)
unnamed: J9.2, J9.4, U5.1 (CANL)
unnamed: J10.1, R5.2
RX_CAN: U5.5 (RXD); also elsewhere on the board
SCL: J4.4, J5.4, J11.4; also elsewhere on the board
SDA: J4.3, J5.3, J11.3; also elsewhere on the board
Saber_3.3V: U7.5 (2A); also elsewhere on the board
Saber_5.0V: R5.1, U7.6 (2Y)
TX_CAN: U5.4 (TXD); also elsewhere on the board
V_IN_5V: J3.2; also elsewhere on the board

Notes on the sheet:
3.3V out
I2C Connectors
Deposition_Feedback
Level Logic Shiting (3.3/5V) Unidirectional
Mounting Holes
LED Connector
General I/O
5V IN
Actuator Feedback Connector
CAN Bus Connector
Analog Input Connectors
SaberTooth Connector

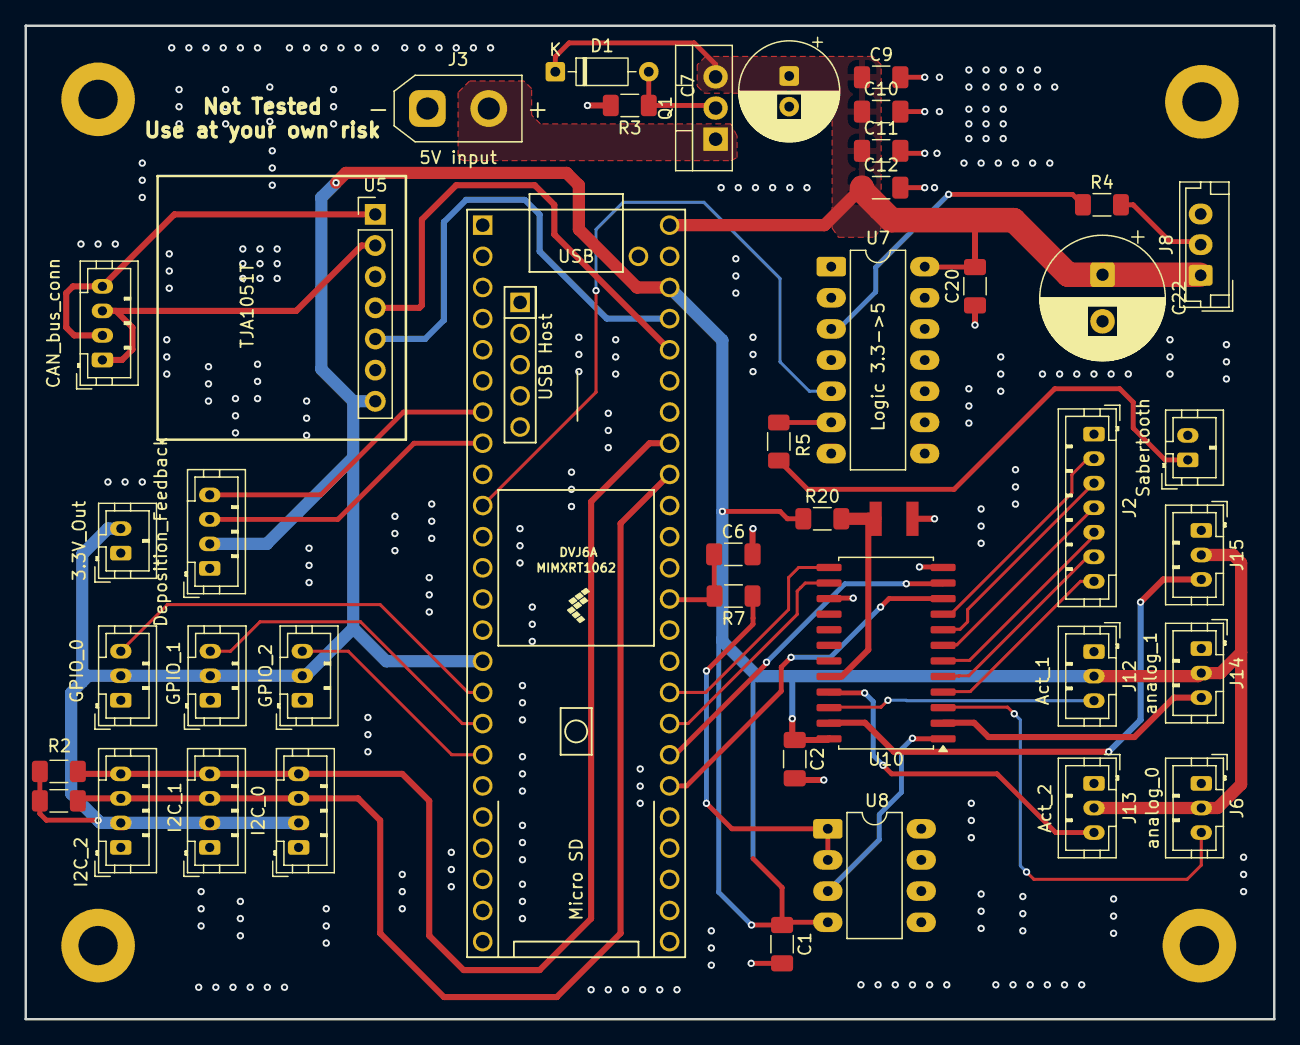
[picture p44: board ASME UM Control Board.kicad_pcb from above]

Board: 4 copper layers, 101.8 x 81.0 mm, 47 parts (0 on the bottom side), 41 nets.

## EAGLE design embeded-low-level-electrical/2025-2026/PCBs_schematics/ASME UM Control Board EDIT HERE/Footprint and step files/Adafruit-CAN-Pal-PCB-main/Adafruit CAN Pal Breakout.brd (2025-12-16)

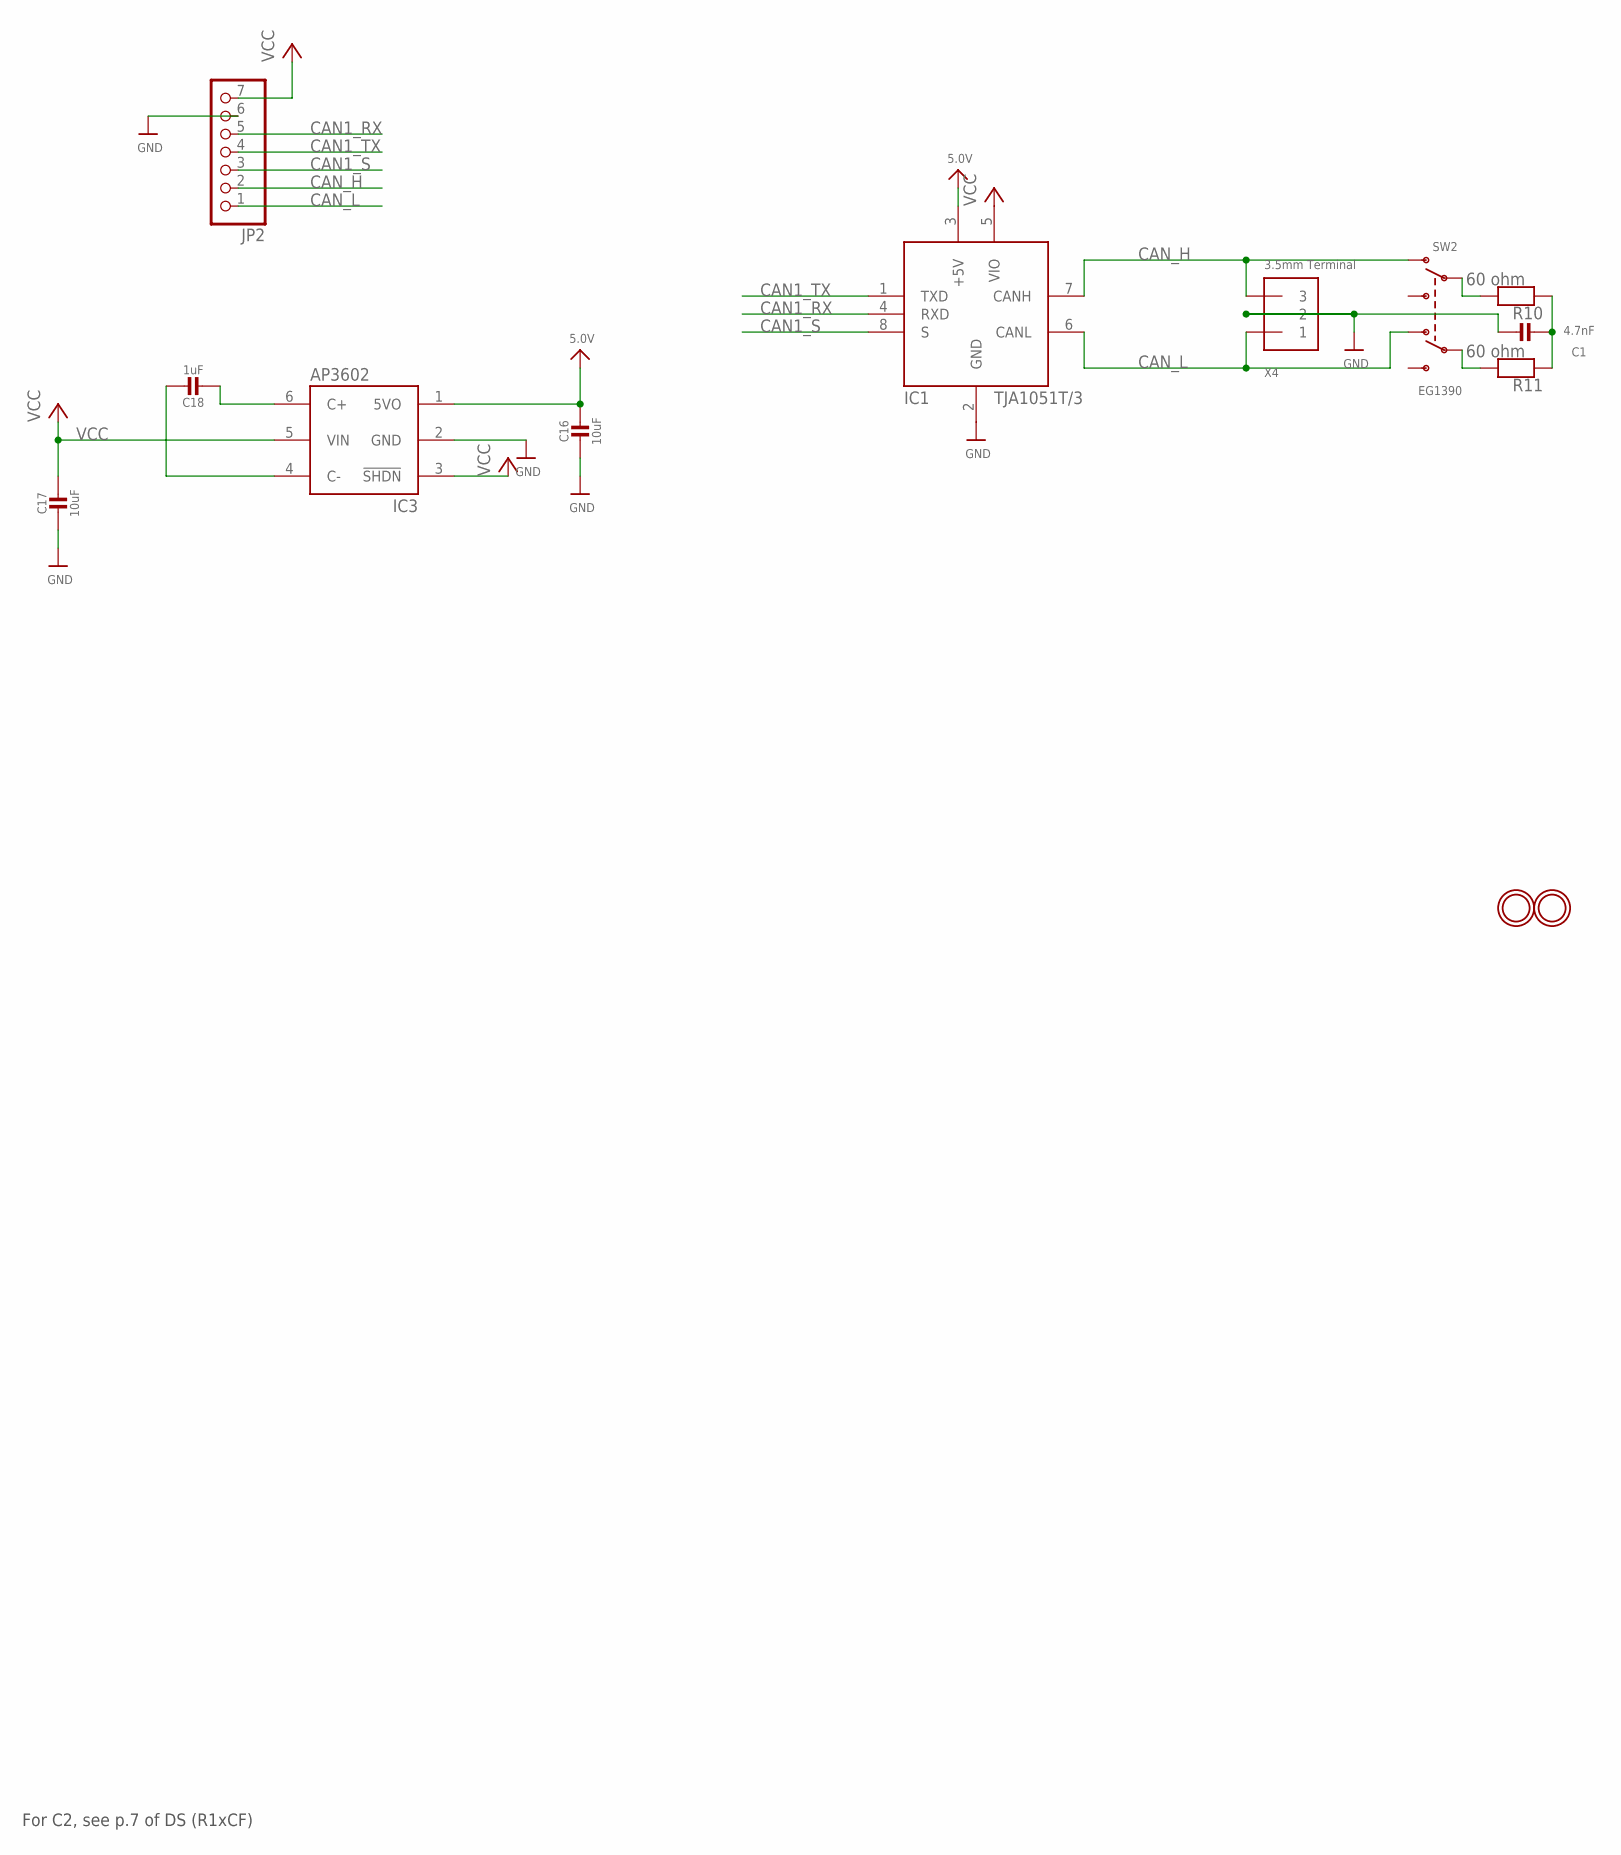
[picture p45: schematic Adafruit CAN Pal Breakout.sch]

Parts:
C1: 4.7nF; 0603-NO
C16, C17: 10uF; 0805-NO
C18: 1uF; 0805_10MGAP
IC1: TJA1051T/3; SOIC8_150MIL
IC3: AP3602; SOT23-6
JP2: HEADER-1X770MIL; 1X07_ROUND_70
R10, R11: 60 ohm; 0603-NO
SW2: EG1390
U$2, U$3: MOUNTINGHOLE2.5; MOUNTINGHOLE_2.5_PLATED
X4: 3.5mm Terminal; TERMBLOCK_1X3-3.5MM

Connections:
5.0V: C16.1, IC1.3 (+5V), IC3.1 (5VO)
CAN1_RX: IC1.4 (RXD), JP2.5
CAN1_S: IC1.8 (S), JP2.3
CAN1_TX: IC1.1 (TXD), JP2.4
CAN_H: IC1.7 (CANH), JP2.2, SW2.O1, X4.3
CAN_L: IC1.6 (CANL), JP2.1, SW2.O2, X4.1
GND: C1.2, C16.2, C17.2, IC1.2 (GND), IC3.2 (GND), JP2.6, X4.2
unnamed: R10.2, SW2.P1
unnamed: R11.2, SW2.P2
unnamed: C18.2, IC3.6 (C+)
unnamed: C18.1, IC3.4 (C-)
unnamed: C1.1, R10.1, R11.1
VCC: C17.1, IC1.5 (VIO), IC3.3 (!SHDN), IC3.5 (VIN), JP2.7

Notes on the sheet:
For C2, see p.7 of DS (R1xCF)

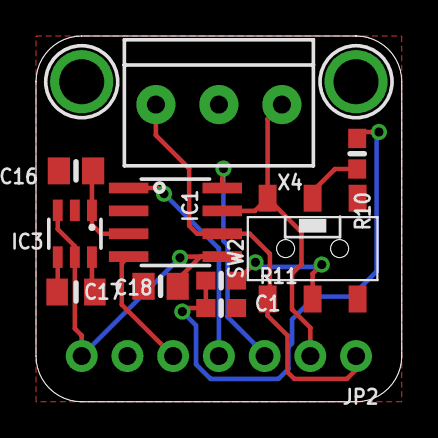
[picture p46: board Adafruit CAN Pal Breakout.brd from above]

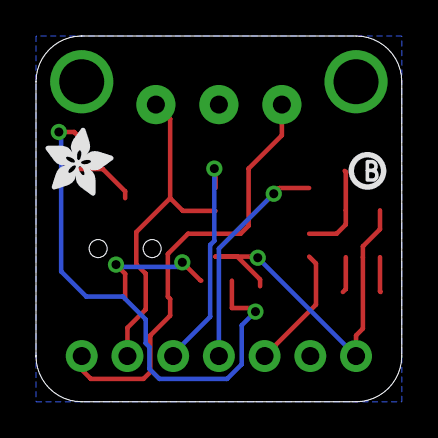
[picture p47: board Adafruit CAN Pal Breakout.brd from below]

Board: 2 copper layers, 20.3 x 20.3 mm, 30 parts (5 on the bottom side), 13 nets.

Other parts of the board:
PLABEL0: PLABEL0
PLABEL1: PLABEL1
PLABEL2: PLABEL2
PLABEL3: PLABEL3
PLABEL4: PLABEL4
PLABEL5: PLABEL5
PLABEL6: PLABEL6
PLABEL7: PLABEL7
PLABEL8: PLABEL8
PLABEL9: PLABEL9
PLABEL10: PLABEL10
PLABEL11: PLABEL11
PLABEL12: PLABEL12
PLABEL13: PLABEL13
PLABEL14: PLABEL14
U$6: ADAFRUIT_3.5MM
U$7: PCBFEAT-REV-040

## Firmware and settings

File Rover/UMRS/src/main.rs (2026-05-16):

// UMRS - University of Miami Robotic System
// UM - ASME
// Version 1.0

mod planner;

use socketcan::{CanSocket, Socket, ExtendedId, CanFrame, Frame, Id, EmbeddedFrame};
use std::thread;
use std::time::{Duration, Instant};
use std::io::{self, Write};
use serde::{Deserialize, Serialize};

use crossterm::event::{poll, read, Event, KeyCode};
use crossterm::terminal::{enable_raw_mode, disable_raw_mode, Clear, ClearType};
use crossterm::cursor::MoveTo;
use crossterm::execute;

const WHEEL_RADIUS_M: f32 = 0.13335; 
const TRACK_WIDTH_M: f32 = 1.06625;     
const GEAR_RATIO: f32 = 64.0;        

const FORWARD_SLIP_MULTIPLIER: f32 = 1.0;
const TURN_SCRUB_MULTIPLIER: f32 = 5.0;

const ENABLE_MOTOR_5: bool = true;
const INVERT_MOTOR_5: bool = false;

const ENABLE_MOTOR_1: bool = true;
const ENABLE_MOTOR_2: bool = true; 
const ENABLE_MOTOR_3: bool = true;
const ENABLE_MOTOR_4: bool = true;

const INVERT_MOTOR_1: bool = false;
const INVERT_MOTOR_2: bool = false;
const INVERT_MOTOR_3: bool = false;
const INVERT_MOTOR_4: bool = false;
const MAP_SIZE: usize = 300; 
const MAP_RES: f32 = 0.05;  
const MAP_OFFSET: f32 = 2.0;
const INFLATION_RADIUS_CELLS: isize = 4; 
const OBSTACLE_ACCEPT_RANGE_M: f32 = 1.0;
const OBSTACLE_CLUSTER_RADIUS_M: f32 = 0.3; 
const CONFIDENCE_ON_DETECT: u8 = 80;
const CONFIDENCE_THRESHOLD: u8 = 40;
const CONFIDENCE_DECAY: u8 = 2;
const OBSTACLE_TTL_SECS: f32 = 4.0;        
const MAX_CONSECUTIVE_REPLANS: u8 = 5;
const TARGET_BERM_X: f32 = 6.80;
const TARGET_BERM_Z: f32 = 2.57;
const TARGET_DIG_X: f32 = 1.00;
const TARGET_DIG_Z: f32 = 1.00;
const BOUNDS_X_MIN: f32 = -0.20;
const BOUNDS_X_MAX: f32 = 7.80; 
const BOUNDS_Z_MIN: f32 = -0.20;  
const BOUNDS_Z_MAX: f32 = 3.57;
const CAL_M: f32 = 42.73;
const CAL_B: f32 = 20.0;
const KP_ACTUATOR: f32 = 0.8;
const ACT_MIN_SPEED: i32 = 12;
const DEADBAND_ADC: i32 = 5; 
const KP_DEPOSITION: f32 = 2.8;
const DEPO_MIN_SPEED: i32 = 20;
const DEADBAND_DEPO_CM: f32 = 0.2;
const ACTUATOR_SPEED_SCALE_DOWN: f32 = 0.3;
const ACTUATOR_SPEED_SCALE_UP: f32 = 1.0;
const DEPOSITION_SPEED_SCALE: f32 = 1.0;
const EXCAVATE_TARGET_DEPTH_CM: f32 = 12.0;     
const EXCAVATE_DIG_MOTOR_EFFORT: f32 = -14.0;   
const EXCAVATE_BELT_PAUSE_SECS: f32 = 2.0;     
const EXCAVATE_BELT_INCREMENT_CM: f32 = -5.0;  
const EXCAVATE_BELT_TOTAL_CM: f32 = -25.0;    
const EXCAVATE_BELT_SETTLE_TIMEOUT_SECS: f32 = 2.0;
const EXCAVATE_DRIVE_EFFORT: f32 = 2.0;        
const EXCAVATE_DRIVE_SPEED_SCALE: f32 = 0.09;     
const DUMP_BELT_TRAVEL_CM: f32 = -43.0;          
const DUMP_BELT_SETTLE_TIMEOUT_SECS: f32 = 5.0; 
const DUMP_BACKOUT_DISTANCE_M: f32 = 1.5;    
const DUMP_IN_DISTANCE_M: f32 = 1.0;
const DUMP_IN_EFFORT: f32 = 2.0;     
const DUMP_IN_SPEED_SCALE: f32 = 0.5;    
const DUMP_BACKOUT_EFFORT: f32 = 2.0;     
const DUMP_BACKOUT_SPEED_SCALE: f32 = 0.5;    
const DUMP_OFFSET_Z_PER_CYCLE: f32 = 0.4;      
const WITH_EXCAVATION: bool = false; 
const WITH_DUMPING: bool = false;
const FAKE_EXCAVATE_SECS: f32 = 5.0; 
const FAKE_DUMP_SECS: f32 = 5.0;     
const ARUCO_CHECK_TIMEOUT_SECS: f32 = 30.0;
const ARUCO_CHECK_SPIN_RPM: f32 = 96.0;
const ARUCO_CHECK_BREATHE_SECS: f32 = 1.5;
const ARUCO_TRUST_CLOSE: f32 = 0.85;    
const ARUCO_TRUST_FAR: f32 = 0.30;     
const ARUCO_TRUST_CLOSE_DIST: f32 = 1.0; 
const ARUCO_TRUST_FAR_DIST: f32 = 7.0; 
const BERM_EXCLUSION_X_MIN: f32 = 6.25;   // 6.80 - 0.55
const BERM_EXCLUSION_X_MAX: f32 = 7.35;   // 6.80 + 0.55
const BERM_EXCLUSION_Z_MIN: f32 = 1.72;   // 2.57 - 0.85
const BERM_EXCLUSION_Z_MAX: f32 = 3.42;   // 2.57 + 0.85

#[derive(PartialEq, Debug, Clone, Copy)]
enum RobotState {
    Manual, 
    Localizing, 
    MissionStart,
    Excavate,
    PlanToBerm,
    PlanToDig,
    AutoTurn, 
    AutoDrive, 
    Dump,
    MissionComplete,
    TestTurn,
    TestExcavate,
    TestDump,
    ArucoCheck,
}

#[derive(Serialize, Deserialize, Debug, Default)]
struct Obstacle {
    #[serde(rename = "type")]
    obs_type: String,
    rel_x: f32,
    rel_z: f32,
}

#[derive(Serialize, Deserialize, Debug, Default)]
struct TelemetryData {
    #[serde(default)] aruco_pos: Vec<f32>,
    #[serde(default)] imu_yaw_rate: f32,
    #[serde(default)] vo_dx: f32,
    #[serde(default)] vo_dz: f32,
    #[serde(default)] localization_mode: String,
    #[serde(default)] vo_status: String, 
    #[serde(default)] obstacles: Vec<Obstacle>,
}

#[derive(Serialize)]
struct SimCommand {
    m1: f32, m2: f32, m3: f32, m4: f32,
    x: f32, z: f32, yaw: f32,
}

struct TrackedObstacle {
    x: f32,
    z: f32,
    last_seen: Instant,
}

fn build_velocity_can_id(device_id: u32) -> ExtendedId {
    let device_type = 2 << 24; let manufacturer = 5 << 16;
    let api_class = 1 << 10; let api_index = 2 << 6;  
    let can_id = device_type | manufacturer | api_class | api_index | device_id;
    ExtendedId::new(can_id).expect("Failed to create ExtendedId for Velocity Command")
}

fn send_velocity_command(socket: &CanSocket, device_id: u32, rpm: f32, invert: bool) {
    let mut final_rpm = rpm;
    if invert { final_rpm = -final_rpm; }
    let id = build_velocity_can_id(device_id);
    let rpm_bytes = final_rpm.to_le_bytes();
    let payload: [u8; 8] = [rpm_bytes[0], rpm_bytes[1], rpm_bytes[2], rpm_bytes[3], 0, 0, 0, 1];
    let frame = CanFrame::new(id, &payload).expect("Failed to construct CAN frame");
    let _ = socket.write_frame(&frame);
}

fn send_sabertooth_command(socket: &CanSocket, act_speed: i16, depo_speed: i16) {
    let id = ExtendedId::new(0x100001).expect("Failed to create ExtendedId for Sabertooth");
    let act_bytes = act_speed.to_le_bytes();
    let depo_bytes = depo_speed.to_le_bytes();
    let payload: [u8; 8] = [
        act_bytes[0], act_bytes[1],
        depo_bytes[0], depo_bytes[1], 
        0, 0, 0, 0
    ];
    let frame = CanFrame::new(id, &payload).expect("Failed to construct CAN frame");
    let _ = socket.write_frame(&frame);
}

const PATH_CHECK_CORRIDOR_CELLS: isize = 5;

fn is_path_blocked(map: &[[u8; MAP_SIZE]; MAP_SIZE], start_x: f32, start_z: f32, goal_x: f32, goal_z: f32) -> bool {
    let mut x0 = ((start_x + MAP_OFFSET) / MAP_RES).round() as isize;
    let mut z0 = ((start_z + MAP_OFFSET) / MAP_RES).round() as isize;
    let x1 = ((goal_x + MAP_OFFSET) / MAP_RES).round() as isize;
    let z1 = ((goal_z + MAP_OFFSET) / MAP_RES).round() as isize;
    let dx = (x1 - x0).abs(); let dz = (z1 - z0).abs();
    let sx = if x0 < x1 { 1 } else { -1 }; let sz = if z0 < z1 { 1 } else { -1 };
    let mut err = dx - dz;

    while x0 != x1 || z0 != z1 {
        for cx in -PATH_CHECK_CORRIDOR_CELLS..=PATH_CHECK_CORRIDOR_CELLS {
            for cz in -PATH_CHECK_CORRIDOR_CELLS..=PATH_CHECK_CORRIDOR_CELLS {
                let check_x = x0 + cx;
                let check_z = z0 + cz;
                if check_x >= 0 && check_x < MAP_SIZE as isize && check_z >= 0 && check_z < MAP_SIZE as isize {
                    if map[check_x as usize][check_z as usize] >= CONFIDENCE_THRESHOLD { return true; }
                }
            }
        }
        let e2 = 2 * err;
        if e2 > -dz { err -= dz; x0 += sx; }
        if e2 < dx { err += dx; z0 += sz; }
    }
    false
}

fn distance_to_boundary(x: f32, z: f32, dx: f32, dz: f32, bx_min: f32, bx_max: f32, bz_min: f32, bz_max: f32) -> f32 {
    let mut t_min = f32::MAX;
    if dx >  0.001 { t_min = t_min.min((bx_max - x) / dx); }
    if dx < -0.001 { t_min = t_min.min((bx_min - x) / dx); }
    if dz >  0.001 { t_min = t_min.min((bz_max - z) / dz); }
    if dz < -0.001 { t_min = t_min.min((bz_min - z) / dz); }
    t_min.max(0.0)
}

fn main() {
    let rx_socket = CanSocket::open("can0").expect("CRITICAL: Failed to open CAN rx_socket");
    rx_socket.set_nonblocking(true).expect("Failed to set CAN socket to non-blocking");
    let tx_socket = CanSocket::open("can0").expect("CRITICAL: Failed to open CAN tx_socket");

    send_velocity_command(&tx_socket, 1, 0.0, false);
    send_velocity_command(&tx_socket, 2, 0.0, false);
    send_velocity_command(&tx_socket, 3, 0.0, false);
    send_velocity_command(&tx_socket, 4, 0.0, false);
    send_velocity_command(&tx_socket, 5, 0.0, false);
    send_sabertooth_command(&tx_socket, 0, 0);
    thread::sleep(Duration::from_millis(50));

    let heartbeat_rx_socket = CanSocket::open("can0").expect("Failed to open heartbeat socket");
    heartbeat_rx_socket.set_nonblocking(true).expect("Failed to set heartbeat socket to non-blocking");

    let context = zmq::Context::new();
    let subscriber = context.socket(zmq::SUB).unwrap();
    subscriber.connect("tcp://localhost:5555").expect("Failed to connect to ZMQ");
    subscriber.set_subscribe(b"").expect("Failed to subscribe to ZMQ");

    let publisher = context.socket(zmq::PUB).unwrap();
    publisher.bind("tcp://*:5556").expect("Failed to bind Sim Publisher");
    let mut print_timer = Instant::now();
    let mut action_timer = Instant::now();
    let mut current_state = RobotState::Manual;
    let mut cycle_count: u8 = 0;
    let mut target_x: f32 = 0.0;
    let mut target_z: f32 = 0.0;
    let mut waypoints: Vec<(f32, f32)> = Vec::new();
    let mut path_status = String::from("IDLE");
    let mut global_x: f32 = 0.50;
    let mut global_z: f32 = 0.50;
    let mut logical_yaw: f32 = std::f32::consts::PI / 2.0;
    let mut loc_mode = String::from("WAITING");
    let mut cfg_target_berm_x: f32 = TARGET_BERM_X;
    let mut cfg_target_berm_z: f32 = TARGET_BERM_Z;
    let mut cfg_target_dig_x: f32 = TARGET_DIG_X;
    let mut cfg_target_dig_z: f32 = TARGET_DIG_Z;
    let mut cfg_bounds_x_min: f32 = BOUNDS_X_MIN;
    let mut cfg_bounds_x_max: f32 = BOUNDS_X_MAX;
    let mut cfg_bounds_z_min: f32 = BOUNDS_Z_MIN;
    let mut cfg_bounds_z_max: f32 = BOUNDS_Z_MAX;
    let mut cfg_berm_excl_x_min: f32 = BERM_EXCLUSION_X_MIN;
    let mut cfg_berm_excl_x_max: f32 = BERM_EXCLUSION_X_MAX;
    let mut cfg_berm_excl_z_min: f32 = BERM_EXCLUSION_Z_MIN;
    let mut cfg_berm_excl_z_max: f32 = BERM_EXCLUSION_Z_MAX;
    let mut cfg_marker_x: f32 = 0.0;
    let mut cfg_marker_z: f32 = 0.0;
    let mut turn_in_progress = false;
    let mut turn_target_pos: f32 = 0.0;
    let mut arena_map = [[0u8; MAP_SIZE]; MAP_SIZE];
    let mut tracked_obstacles: Vec<TrackedObstacle> = Vec::new();
    let mut show_map = false; 
    let mut consecutive_replans: u8 = 0;
    let mut berm_exclusion_active: bool = false;
    let mut base_speed: f32 = 160.0;
    let mut excavation_speed: f32 = 80.0;
    let mut cmd_m1: f32 = 0.0; 
    let mut cmd_m2: f32 = 0.0; 
    let mut cmd_m3: f32 = 0.0; 
    let mut cmd_m4: f32 = 0.0;
    let mut cmd_m5: f32 = 0.0;
    let mut act_speed: i16 = 0; 
    let mut depo_speed: i16 = 0; 
    let mut actual_rpm_m1: f32 = 0.0; 
    let mut actual_rpm_m2: f32 = 0.0; 
    let mut actual_rpm_m3: f32 = 0.0; 
    let mut actual_rpm_m4: f32 = 0.0;
    let mut actual_rpm_m5: f32 = 0.0;
    let mut actual_pos_m1: f32 = 0.0;
    let mut imu_yaw_deg: f32 = 0.0;
    let mut imu_pitch_deg: f32 = 0.0;
    let mut imu_roll_deg: f32 = 0.0;
    let mut current_adc_reading: i32 = 0;
    let mut current_depo_cm: f32 = 0.0;
    let mut initial_depo_offset: Option<f32> = None;
    let mut target_depth_cm: Option<f32> = None;
    let mut target_depo_cm: Option<f32> = None;
    let mut error_ticks: i32 = 0;
    let mut error_depo: f32 = 0.0;
    let mut excavate_phase: u8 = 0;
    let mut excavate_belt_laps_done: u32 = 0;
    let excavate_belt_total_laps: u32 = (EXCAVATE_BELT_TOTAL_CM / EXCAVATE_BELT_INCREMENT_CM).round() as u32;
    let mut excavate_belt_paused: bool = false;
    let mut dump_phase: u8 = 0;
    let mut dump_backout_start_x: f32 = 0.0;
    let mut dump_backout_start_z: f32 = 0.0;
    let mut dump_backout_forward: bool = false; 
    let mut aruco_check_phase: u8 = 0;
    let mut aruco_check_pre_yaw: f32 = 0.0;    
    let mut aruco_check_resume_state: u8 = 0;  
    let mut aruco_check_got_fix: bool = false;  
    let mut aruco_check_timer = Instant::now();
    let mut aruco_check_spin_sign: f32 = 1.0;
    let mut last_kinematics_time = Instant::now();
    let mut imu_turning_active: bool = false;
    let mut imu_turn_start_deg: f32 = 0.0;

    enable_raw_mode().expect("Failed to enable raw mode");
    execute!(io::stdout(), Clear(ClearType::All)).unwrap();

    thread::spawn(move || {
        let heartbeat_id = ExtendedId::new(0x02052C80).unwrap();
        let heartbeat_frame = CanFrame::new(heartbeat_id, &[0xFF; 8]).unwrap();
        let hb_tx_socket = CanSocket::open("can0").unwrap();
        loop {
            while let Ok(_) = heartbeat_rx_socket.read_frame() {} 
            let _ = hb_tx_socket.write_frame(&heartbeat_frame);
            thread::sleep(Duration::from_millis(20));
        }
    });

    loop {
        if poll(Duration::from_millis(0)).unwrap() {
            if let Event::Key(key_event) = read().unwrap() {
                match key_event.code {
                    KeyCode::Char('m') | KeyCode::Char('M') | KeyCode::Char(' ') => {
                        current_state = RobotState::Manual;
                        cmd_m1 = 0.0; cmd_m2 = 0.0; cmd_m3 = 0.0; cmd_m4 = 0.0; cmd_m5 = 0.0; 
                        act_speed = 0; 
                        depo_speed = 0; 
                        
                        target_depth_cm = Some((current_adc_reading as f32 - CAL_B) / CAL_M);
                        target_depo_cm = Some(current_depo_cm);
                        
                        path_status = String::from("ABORTED");
                        consecutive_replans = 0;
                        berm_exclusion_active = false;
                    },
                    KeyCode::Char('l') | KeyCode::Char('L') => {
                        current_state = RobotState::Localizing;
                        cmd_m1 = 0.0; cmd_m2 = 0.0; cmd_m3 = 0.0; cmd_m4 = 0.0; cmd_m5 = 0.0;
                    },
                    KeyCode::Char('p') | KeyCode::Char('P') => { show_map = !show_map; execute!(io::stdout(), Clear(ClearType::All)).unwrap(); },
                    KeyCode::Char('g') | KeyCode::Char('G') => {
                        if current_state == RobotState::Localizing || current_state == RobotState::Manual {
                            disable_raw_mode().expect("Failed to disable raw mode");
                            execute!(io::stdout(), MoveTo(0, 0), Clear(ClearType::All)).unwrap();

                            println!("=============================================");
                            println!("       ARENA CONFIGURATION — PRESS 1 OR 2    ");
                            println!("=============================================");
                            println!("  Option 1 (Default — ArUco at origin):");
                            println!("    Berm:  ({:.2}, {:.2})", TARGET_BERM_X, TARGET_BERM_Z);
                            println!("    Dig:   ({:.2}, {:.2})", TARGET_DIG_X, TARGET_DIG_Z);
                            println!("    Start: (0.50, 0.50)  ArUco (0, 0)");
                            println!("");
                            println!("  Option 2 (Secondary — ArUco at Z=6):");
                            println!("    Berm:  (6.80, 1.57)");
                            println!("    Dig:   (1.00, 6.00)");
                            println!("    Start: (0.50, 5.50)  ArUco (0, 6)");
                            println!("=============================================");
                            print!("Select (1/2): ");
                            io::stdout().flush().unwrap();

                            let mut input = String::new();
                            let mut selected = 1u8;
                            if io::stdin().read_line(&mut input).is_ok() {
                                if input.trim() == "2" { selected = 2; }
                            }

                            if selected == 2 {
                                cfg_target_berm_x = 6.80;
                                cfg_target_berm_z = 1.57;
                                cfg_target_dig_x = 1.00;
                                cfg_target_dig_z = 6.00;
                                global_x = 0.50;
                                global_z = 5.50;
                                logical_yaw = std::f32::consts::PI / 2.0;
                                cfg_bounds_x_min = BOUNDS_X_MIN;
                                cfg_bounds_x_max = BOUNDS_X_MAX;
                                cfg_bounds_z_min = -0.20;
                                cfg_bounds_z_max = 7.00;
                                cfg_berm_excl_x_min = BERM_EXCLUSION_X_MIN;
                                cfg_berm_excl_x_max = BERM_EXCLUSION_X_MAX;
                                cfg_berm_excl_z_min = 0.72;
                                cfg_berm_excl_z_max = 2.42;
                                cfg_marker_x = 0.0;
                                cfg_marker_z = 6.0;
                            } else {
                                cfg_target_berm_x = TARGET_BERM_X;
                                cfg_target_berm_z = TARGET_BERM_Z;
                                cfg_target_dig_x = TARGET_DIG_X;
                                cfg_target_dig_z = TARGET_DIG_Z;
                                global_x = 0.50;
                                global_z = 0.50;
                                logical_yaw = std::f32::consts::PI / 2.0;
                                cfg_bounds_x_min = BOUNDS_X_MIN;
                                cfg_bounds_x_max = BOUNDS_X_MAX;
                                cfg_bounds_z_min = BOUNDS_Z_MIN;
                                cfg_bounds_z_max = BOUNDS_Z_MAX;
                                cfg_berm_excl_x_min = BERM_EXCLUSION_X_MIN;
                                cfg_berm_excl_x_max = BERM_EXCLUSION_X_MAX;
                                cfg_berm_excl_z_min = BERM_EXCLUSION_Z_MIN;
                                cfg_berm_excl_z_max = BERM_EXCLUSION_Z_MAX;
                                cfg_marker_x = 0.0;
                                cfg_marker_z = 0.0;
                            }

                            enable_raw_mode().expect("Failed to enable raw mode");
                            execute!(io::stdout(), Clear(ClearType::All)).unwrap();

                            current_state = RobotState::MissionStart;
                            consecutive_replans = 0;
                        }
                    },
                    KeyCode::Esc | KeyCode::Char('q') | KeyCode::Char('Q') => { break; },
                    
                    KeyCode::Char('1') => {
                        if current_state == RobotState::Manual || current_state == RobotState::Localizing {
                            turn_target_pos = logical_yaw + (std::f32::consts::PI / 2.0);
                            while turn_target_pos > std::f32::consts::PI { turn_target_pos -= 2.0 * std::f32::consts::PI; }
                            while turn_target_pos < -std::f32::consts::PI { turn_target_pos += 2.0 * std::f32::consts::PI; }
                            current_state = RobotState::TestTurn;
                            path_status = String::from("TEST TURN 90 RIGHT");
                        }
                    },
                    KeyCode::Char('2') => {
                        if current_state == RobotState::Manual || current_state == RobotState::Localizing {
                            turn_target_pos = logical_yaw - (std::f32::consts::PI / 2.0); 
                            while turn_target_pos > std::f32::consts::PI { turn_target_pos -= 2.0 * std::f32::consts::PI; }
                            while turn_target_pos < -std::f32::consts::PI { turn_target_pos += 2.0 * std::f32::consts::PI; }
                            current_state = RobotState::TestTurn;
                            path_status = String::from("TEST TURN 90 LEFT");
                        }
                    },
                    KeyCode::Char('3') => {
                        if current_state == RobotState::Manual || current_state == RobotState::Localizing {
                            turn_target_pos = logical_yaw + std::f32::consts::PI; 
                            while turn_target_pos > std::f32::consts::PI { turn_target_pos -= 2.0 * std::f32::consts::PI; }
                            while turn_target_pos < -std::f32::consts::PI { turn_target_pos += 2.0 * std::f32::consts::PI; }
                            current_state = RobotState::TestTurn;
                            path_status = String::from("TEST TURN 180 DEG");
                        }
                    },

                    KeyCode::Char('7') => {
                        if current_state == RobotState::Manual || current_state == RobotState::Localizing {
                            excavate_phase = 0;
                            excavate_belt_laps_done = 0;
                            excavate_belt_paused = false;
                            current_state = RobotState::TestExcavate;
                            action_timer = Instant::now();
                            path_status = String::from("TEST EXCAVATION STARTED");
                        }
                    },

                    KeyCode::Char('9') => {
                        if current_state == RobotState::Manual || current_state == RobotState::Localizing {
                            dump_phase = 0;
                            dump_backout_start_x = global_x;
                            dump_backout_start_z = global_z;
                            current_state = RobotState::TestDump;
                            action_timer = Instant::now();
                            path_status = String::from("TEST DUMP STARTED");
                        }
                    },
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

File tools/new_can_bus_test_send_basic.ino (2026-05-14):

/*
Name: Ahmed Ahmed, Ahmed Ahmed Ahmed
Company: ASME UM
Project: Autonomous Rover + NeoPixel Status
Purpose: Integrated 16-channel MUX, Sabertooth Motor Control via CAN,
         Encoder telemetry, NeoPixel status strip, and LSM9DS1 IMU YPR.
*/

#include <Arduino.h>
#include <Wire.h>
#include <SPI.h>

#include <FlexCAN_T4.h>
#include <Encoder.h>
#include <Adafruit_NeoPixel.h>

#include <SparkFunLSM9DS1.h>
#include <MadgwickAHRS.h>

/* --- Hardware Definitions --- */
#define SabertoothSerial Serial2
const int LED_PIN = 13;      // Onboard Teensy LED

// NeoPixel Definitions
#define PIXEL_PIN    A7      // Data pin for LEDs
#define NUMPIXELS    100     // Number of pixels
#define PIXEL_DELAY  100     // Animation speed

// Sabertooth Addresses
const byte ADDR_129 = 129;
const byte ADDR_130 = 130;

// MUX Pin Definitions
const int S0 = 38;
const int S1 = 39;
const int S2 = 40;
const int S3 = 41;
const int SIG_PIN = A0;
const int ACTUATOR_MUX_CH = 9;

/* --- IMU Settings --- */
const float SAMPLE_RATE_HZ = 100.0;
unsigned long microsPerReading = 0;
unsigned long microsPrevious = 0;

const int GYRO_CAL_SAMPLES = 30000;
const int GYRO_CAL_DELAY_MS = 1;

float gxBias = -0.724494;
float gyBias = -2.545511;
float gzBias = 1.893234;

float yawDeg = 0.0;
float pitchDeg = 0.0;
float rollDeg = 0.0;
float yawOffsetDeg = 0.0;

/* --- Object Initialization --- */
Encoder myEnc(6, 5);
FlexCAN_T4<CAN1, RX_SIZE_256, TX_SIZE_16> Can1;
Adafruit_NeoPixel pixels(NUMPIXELS, PIXEL_PIN, NEO_GRB + NEO_KHZ800);

LSM9DS1 imu;
Madgwick filter;

/* --- Timing & State Variables --- */
const float STEPS_PER_CM = 844.27;
unsigned long lastCommandTime = 0;
const int commandTimeout = 1000;

unsigned long lastCanSendTime = 0;
const int canSendInterval = 100;

unsigned long lastPixelUpdate = 0;
bool pixelToggleState = false;

/* --- Function Prototypes --- */
void drive(byte address, byte command, byte data, String label = "");
void stopAllMotors();
void onReceiveCan(const CAN_message_t &msg);
void selectChannel(const uint8_t channel);
void sendTelemetry();
void sendImuTelemetry();
void updateStatusLEDs();

void updateIMU();
float wrap180(float angleDeg);
int16_t degToCentideg(float angleDeg);

void setup() {
  pinMode(LED_PIN, OUTPUT);
  digitalWrite(LED_PIN, HIGH);

  // MUX Setup
  pinMode(S0, OUTPUT);
  pinMode(S1, OUTPUT);
  pinMode(S2, OUTPUT);
  pinMode(S3, OUTPUT);
  pinMode(SIG_PIN, INPUT);

  Serial.begin(115200);
  Wire.begin();

  // IMU Setup
  if(imu.begin()) {
    Serial.println("LSM9DS1 connected.");
  }


  filter.begin(SAMPLE_RATE_HZ);
  microsPerReading = 1000000UL / SAMPLE_RATE_HZ;
  microsPrevious = micros();

  // NeoPixel Setup
  pixels.begin();
  pixels.setBrightness(50);
  pixels.show();

  SabertoothSerial.begin(9600);

  // CAN Bus Setup
  Can1.begin();
  Can1.setBaudRate(1000000);
  Can1.setMaxMB(16);
  Can1.enableFIFO();
  Can1.enableFIFOInterrupt();
  Can1.onReceive(onReceiveCan);

  delay(2000);
  SabertoothSerial.write(170); // Sabertooth handshake
  delay(100);

  stopAllMotors();
  Serial.println(">>> BOOT SUCCESSFUL: ROVER, LEDS, IMU ACTIVE <<<");
}

void loop() {
  Can1.events();

  // Update IMU at fixed rate
  updateIMU();

  // Blink Onboard LED, Teensy heartbeat
  digitalWrite(LED_PIN, (millis() / 500) % 2);

  // Safety Timeout: Stop motors if Jetson goes offline
  if (millis() - lastCommandTime > commandTimeout) {
    stopAllMotors();
  }

  // Non-blocking CAN Transmission
  if (millis() - lastCanSendTime >= canSendInterval) {
    lastCanSendTime = millis();

    sendTelemetry();     // Existing encoder + actuator telemetry
    sendImuTelemetry();  // New YPR telemetry
  }

  // Non-blocking LED Update
  if (millis() - lastPixelUpdate >= PIXEL_DELAY) {
    lastPixelUpdate = millis();
    updateStatusLEDs();
  }
}

/* --- IMU Logic --- */

void updateIMU() {
  unsigned long microsNow = micros();

  if (microsNow - microsPrevious >= microsPerReading) {
    if (imu.accelAvailable()) {
      imu.readAccel();
    }

    if (imu.gyroAvailable()) {
      imu.readGyro();
    }

    // Madgwick expects accel in g and gyro in deg/s
    float ax = imu.calcAccel(imu.ax);
    float ay = imu.calcAccel(imu.ay);
    float az = imu.calcAccel(imu.az);

    float gx = imu.calcGyro(imu.gx) - gxBias;
    float gy = imu.calcGyro(imu.gy) - gyBias;
    float gz = imu.calcGyro(imu.gz) - gzBias;

    // IMU-only fusion: accel + gyro, no magnetometer
    filter.updateIMU(gx, gy, gz, ax, ay, az);

    float rawYaw = filter.getYaw();

    yawDeg = wrap180(rawYaw - yawOffsetDeg);
    pitchDeg = filter.getPitch();
    rollDeg = filter.getRoll();

    microsPrevious += microsPerReading;
  }
}

float wrap180(float angleDeg) {
  while (angleDeg > 180.0) angleDeg -= 360.0;
  while (angleDeg < -180.0) angleDeg += 360.0;
  return angleDeg;
}

int16_t degToCentideg(float angleDeg) {
  angleDeg = wrap180(angleDeg);

  float scaled = angleDeg * 100.0;

  if (scaled > 32767.0) scaled = 32767.0;
  if (scaled < -32768.0) scaled = -32768.0;

  return (int16_t)scaled;
}

/* --- NeoPixel Logic, Non-Blocking --- */

void updateStatusLEDs() {
  pixelToggleState = !pixelToggleState;

  for (int i = 7; i < NUMPIXELS; i++) {
    if ((i % 2 == 0) == pixelToggleState) {
      pixels.setPixelColor(i, pixels.Color(0, 255, 0));    // Green
    } else {
      pixels.setPixelColor(i, pixels.Color(255, 140, 0));  // Orange
    }
  }

  pixels.show();
}

/* --- Telemetry Functions --- */

void sendTelemetry() {
  selectChannel(ACTUATOR_MUX_CH);
  delayMicroseconds(50);

  uint16_t current_adc = analogRead(SIG_PIN);
  long current_steps = myEnc.read();
  float distance_cm = current_steps / STEPS_PER_CM;

  CAN_message_t txmsg;
  txmsg.id = 0x200001;
  txmsg.flags.extended = 1;
  txmsg.len = 6;

  txmsg.buf[0] = current_adc & 0xFF;
  txmsg.buf[1] = (current_adc >> 8) & 0xFF;
  memcpy(&txmsg.buf[2], &distance_cm, sizeof(distance_cm));

  Can1.write(txmsg);
}

void sendImuTelemetry() {
  int16_t yaw_cd   = degToCentideg(yawDeg);
  int16_t pitch_cd = degToCentideg(pitchDeg);
  int16_t roll_cd  = degToCentideg(rollDeg);

  CAN_message_t txmsg;
  txmsg.id = 0x200002;
  txmsg.flags.extended = 1;
  txmsg.len = 6;

  memcpy(&txmsg.buf[0], &yaw_cd, sizeof(int16_t));
  memcpy(&txmsg.buf[2], &pitch_cd, sizeof(int16_t));
  memcpy(&txmsg.buf[4], &roll_cd, sizeof(int16_t));

  Can1.write(txmsg);

  Serial.print("YPR: ");
  Serial.print(yawDeg, 2);
  Serial.print(", ");
  Serial.print(pitchDeg, 2);
  Serial.print(", ");
  Serial.println(rollDeg, 2);
}

/* --- Receive & Control Functions --- */
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

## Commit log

2025-08-29 docs: Add README for electrical schematics
2025-09-05 docs: Add sensors and actuators sections to README
    Added sections for sensors and actuators in README.
2025-11-21 Add some schematics
    [Rover_Board_V1.1_ahmed.kicad_sch, Rover_Board_V1.kicad_sch]
2025-12-08 Added some folders
    [Rover_Board_V1.1_ahmed.kicad_sch, Rover_Board_V1.kicad_sch]
2025-12-13 Added example for the REV BLDC
2025-12-13 Fix typo in HEARTBEAT_ID comment
    [control_speed_spark_max_mcp2515_example.ino]
2025-12-16 added new folders
    [Adafruit CAN Pal Breakout.brd, Adafruit CAN Pal Breakout.sch]
2026-01-02 changed the folder title
    [Rover_Board_V1.1_ahmed.kicad_sch, Rover_Board_V1.kicad_sch]
2026-01-02 deleted folder
    [Adafruit CAN Pal Breakout.brd, Adafruit CAN Pal Breakout.sch]
2026-01-02 change content of the folder
    [Rover_Board_V1.1_ahmed.kicad_sch, Rover_Board_V1.kicad_sch]
2026-01-12 upload pcb and schematics
    [5708 CAN Pal.step, ASME UM Control Board.kicad_pcb, ASME UM Control Board.kicad_sch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]
2026-01-12 Fix image source in README for control board
2026-01-13 Add README content for High-Current Power Distribution Board
    Added detailed overview, features, and specifications for the High-Current Power Distribution Board.
2026-01-13 Clarify motor types in README.md
    Updated motor specifications for clarity.
2026-01-13 Revise PCB design considerations in README.md
    Updated PCB design considerations for high-current optimization, component layout, and power integrity analysis. Added figures for current density simulations before and after optimization.
2026-01-13 Revise README with updated images and design objectives
    Updated image alt texts and added final board design section.
2026-01-13 Add final board design to README
    Added final board design section with image.
2026-01-13 Update README with final board design section
    Added final board design image to README.
2026-01-29 Update README with link to PCB details
2026-01-29 Update README with link to PCB schematics
2026-01-29 add new files
    [BLDC_Conn.kicad_sch, Connectors_box.kicad_pcb, Deposition_and_Actuators_conn.kicad_sch]
2026-05-13 feat: add IMU integration from Russell Code, add ZMQ subscriber
2026-05-13 feat: script that lists devices and available streams
2026-05-16 Revise ArUco pose handling and payload
    Refactor perception pipeline to use camera-frame ArUco tvecs/yaw and remove interactive arena setup. Key changes:
    - Update MARKER_SIZE_METERS (0.20 -> 0.175) and add note that rear camera now sends raw tvecs + yaw; main rover code should perform arena transforms.
    - Remove interactive arena_choice prompt and hardcoded arena transforms; keep MARKER_GLOBAL_X/Z for compatibility.
    - Add calibrated rear camera_matrix and zero dist_coeffs used for pose estimates.
    - Introduce helper functions: wrap_to_pi, estimate_pose_single_marker (with estimatePoseSingleMarkers fallback to solvePnP), and rvec_to_yaw (preserves previous yaw correction convention).
    - Change A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
2026-05-16 Add CAN rover control and telemetry tool
    Add Rover/Tools/new_can.ino: a new CAN-enabled control and telemetry tool for the autonomous rover. Integrates Sabertooth serial motor commands, FlexCAN receive/send handlers, encoder-based distance 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
2026-05-16 Add mainrs.txt for ArUco and IMU localization

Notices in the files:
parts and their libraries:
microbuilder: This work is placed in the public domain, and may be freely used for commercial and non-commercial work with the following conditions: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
